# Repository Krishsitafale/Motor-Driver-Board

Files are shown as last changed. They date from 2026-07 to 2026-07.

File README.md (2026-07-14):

# TeleOps Motor Driver PCB
### International Rover Challenge (IRC) 2026 | Team Vishwa, VJTI






## Overview

The **TeleOps Motor Driver PCB** is a custom-designed embedded motor control board developed for **Team Vishwa, VJTI** for the **International Rover Challenge (IRC) 2026**.

The objective of this board was to consolidate multiple motor driver modules, PWM generators, power regulators, and peripheral interfaces into a single reliable PCB capable of controlling the rover's complete teleoperation subsystem.

Unlike conventional rover electronics that rely on several separate modules connected with extensive wiring, this PCB integrates all essential electronics into one compact system, improving reliability, reducing wiring complexity, and simplifying maintenance during competitions.

## Features

- ESP32-S3 based control unit
- Custom 5V Buck Converter (TPS54302)
- 10 High Current H-Bridge Drivers (BTN9970LV)
- PCA9685 16-Channel PWM Expander
- Encoder Interfaces
- GPS Interface
- Servo Motor Support
- Modular Connectors
- High Current PCB Layout
- Designed specifically for IRC Rover

## Hardware Specifications

| Component | Description |
|---|---|
| Microcontroller | ESP32-S3 |
| Buck Converter | TPS54302 |
| Motor Driver  | BTN9970LV |
| PWM Expansion | PCA9685 |
| Logic Voltage | 3.3V |
| Motor Supply  | 12V |
| PCB | 2 Layer |
| Communication | I²C, GPIO, PWM |

# System Architecture

                         12V Battery
                              │
                ┌─────────────┴─────────────┐
                │                           │
                │                    Motor Supply
                │                           │
                ▼                           ▼
      TPS54302 Buck Converter      10× BTN9970LV Drivers
                │
                ▼
             5V Rail
                │
                ▼
           ESP32-S3 MCU
                │
      ┌─────────┼─────────────────────────────┐
      │         │                             │
      │         │ I²C                         │ Native PWM
      │         ▼                             ▼
      │     PCA9685                    ESP32 PWM Outputs
      │   (16 Channel PWM)             (LEDC Peripheral)
      │         │                             │
      │         │                             ├──────── 2 DC Motor Drivers
      │         │                             │
      │         │                             └──────── 4 Servo Motors
      │         │
      │         ├──────── 8 Motor Driver PWM Inputs
      │         │
      │         └──────── Future Expansion
      │
      ├──────── Encoder Inputs
      │
      ├──────── GPS Interface
      │
      └──────── Programming Interface

## Motor Control Architecture

The rover requires control of multiple actuators with independent PWM channels. To efficiently utilize the ESP32's peripherals, the PWM generation is divided as follows:

| PWM Source | Devices Controlled |
|---|---|
| PCA9685(PWM Expander) | 8 High-Power DC Motor Drivers |
| ESP32 Native PWM | 2 High-Power DC Motor Drivers |
| ESP32 Native PWM | 4 Servo Motors |

This hybrid architecture reduces the processing load on the ESP32 while providing highly stable PWM signals for the drivetrain and robotic arm.

## Supported Actuators

### Drive System

- 6 Planetary DC Motors

### Robotic Arm

- 3 Stepper Motors
- 1 Planetary DC Motor
- 2 Worm Gear Motors
- 4 Servo Motors

### Sensors

- OE775 Quadrature Encoders
- GPS Module

## PCB Highlights

- Dedicated power plane for motor supply
- Optimized ground routing
- High-current copper traces
- Decoupling for every IC
- Modular connector layout
- Compact footprint
- Easy debugging headers
- Competition-ready wiring

## Testing

The PCB has successfully passed the following validation tests.

- Power Supply Verification
- ESP32 Programming
- Buck Converter Efficiency Test
- PCA9685 Communication
- PWM Signal Verification
- Motor Driver Validation
- Encoder Testing
- Servo Testing
- Thermal Performance
- Complete System Integration

## Future Improvements

- Closed Loop Motor Control
- Current Monitoring
- Battery Voltage Monitoring
- CAN Bus Support
- IMU Integration
- OTA Firmware Updates
- ROS 2 Compatibility

## Gallery

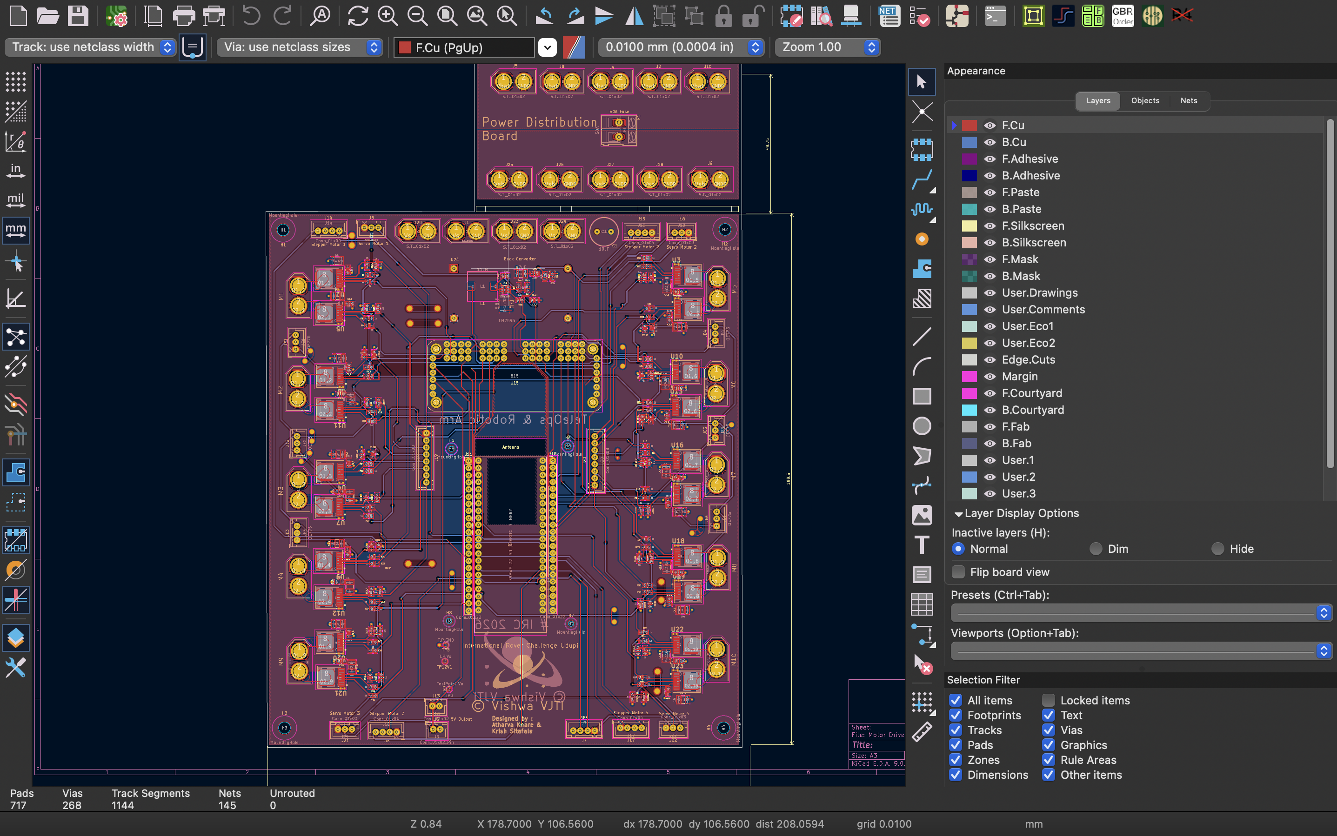
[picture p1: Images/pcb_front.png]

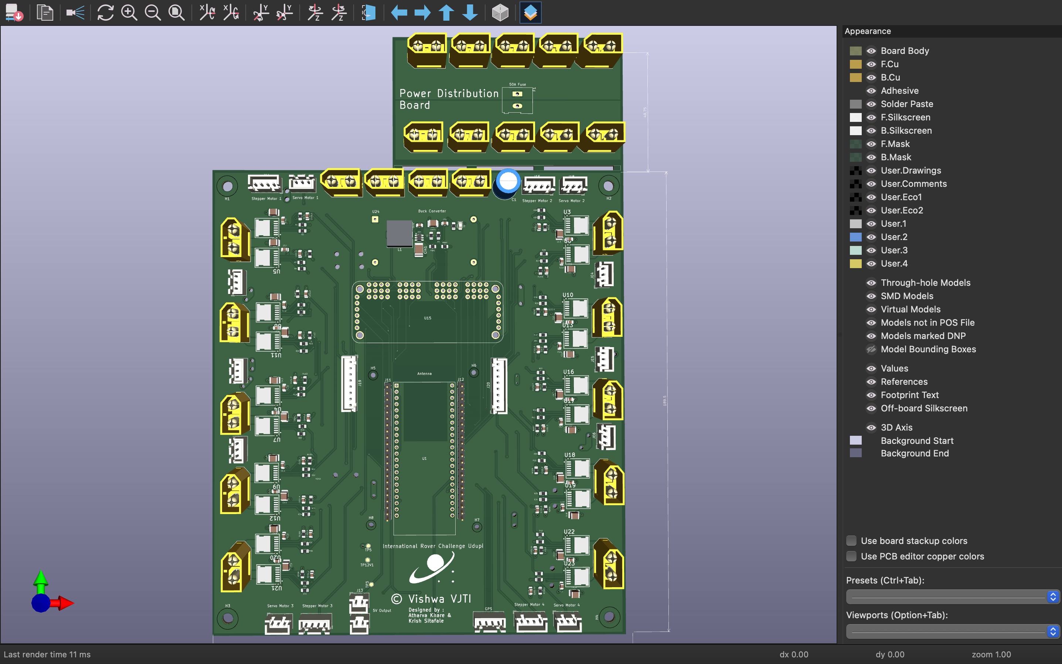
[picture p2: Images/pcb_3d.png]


## Acknowledgements

This PCB was designed and developed as part of the **Electronics Subsystem** of **Team Vishwa, VJTI** for the **International Rover Challenge (IRC) 2026**.

Special thanks to **Atharva Khare** for his invaluable guidance throughout the design, debugging, and testing phases of the project.

## Author

**Krish Sitafale**

Electronics & Telecommunication Engineering  
Veermata Jijabai Technological Institute (VJTI), Mumbai

Team Vishwa – IRC 2026

## License

This project is released for educational and research purposes.

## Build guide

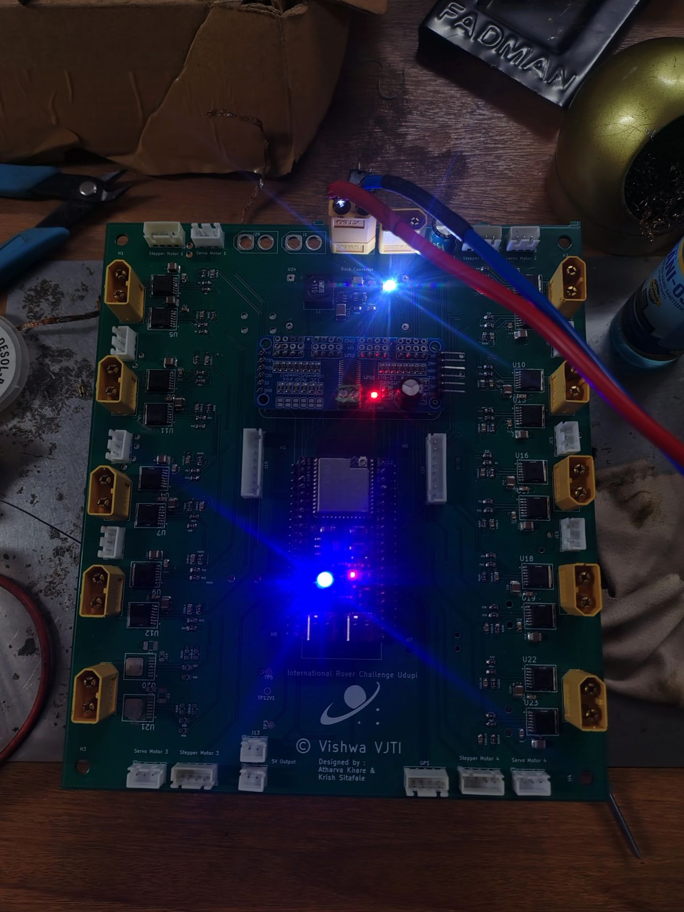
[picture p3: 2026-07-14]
Images/assembled_board.png

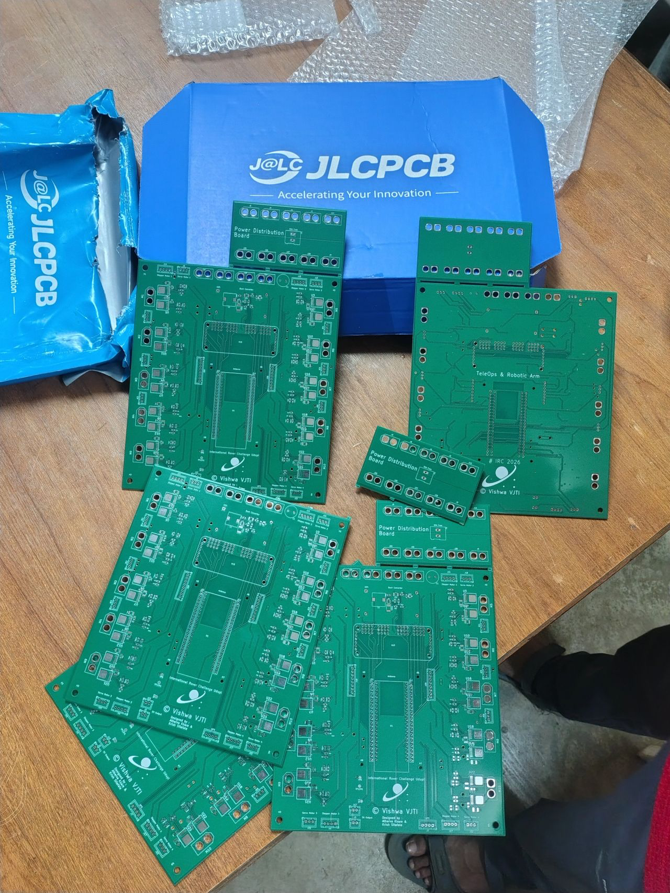
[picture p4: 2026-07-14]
Images/fabricated_board.png

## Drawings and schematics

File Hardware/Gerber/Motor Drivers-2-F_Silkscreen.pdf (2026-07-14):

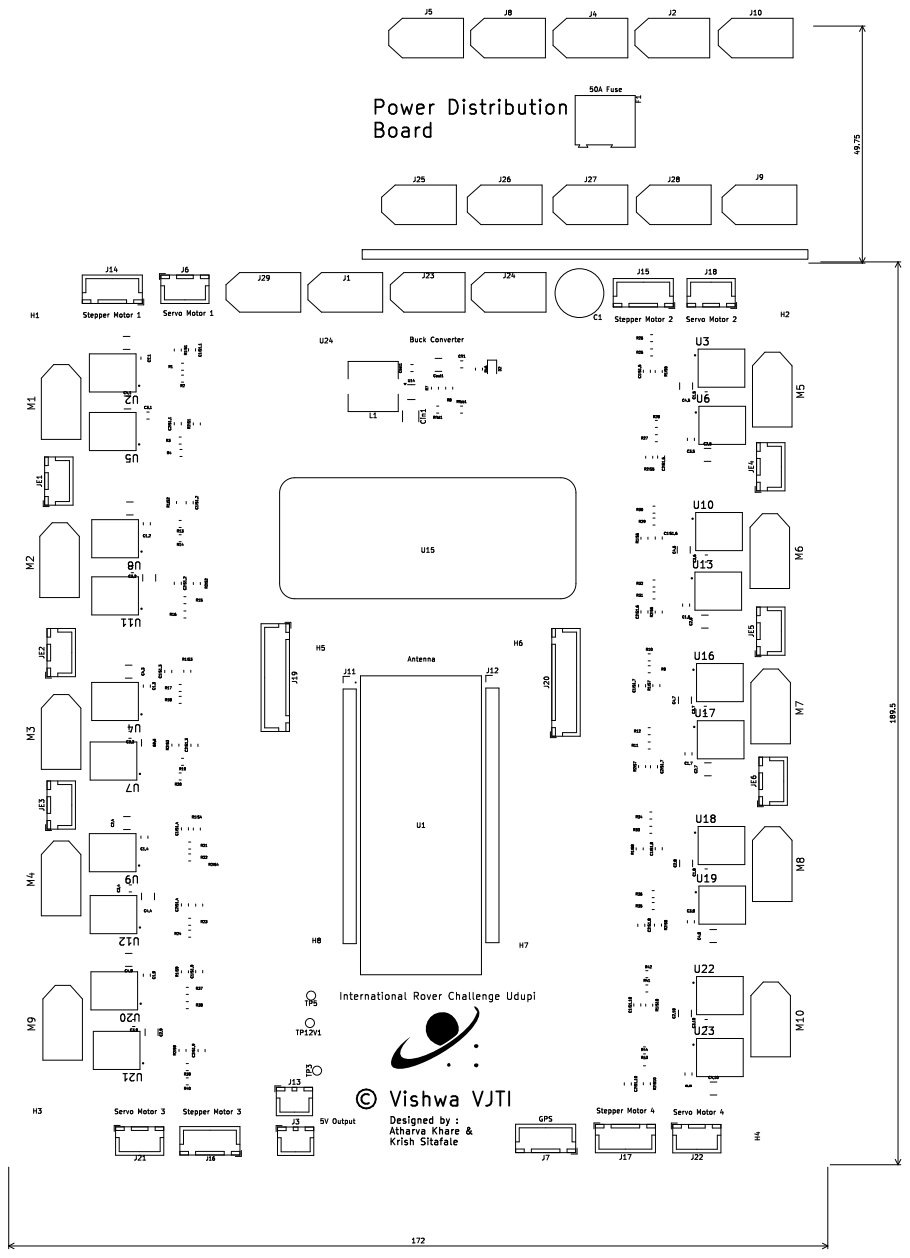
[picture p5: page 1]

Stepper Motor 2 Stepper Motor 1

Designed by : Atharva Khare &

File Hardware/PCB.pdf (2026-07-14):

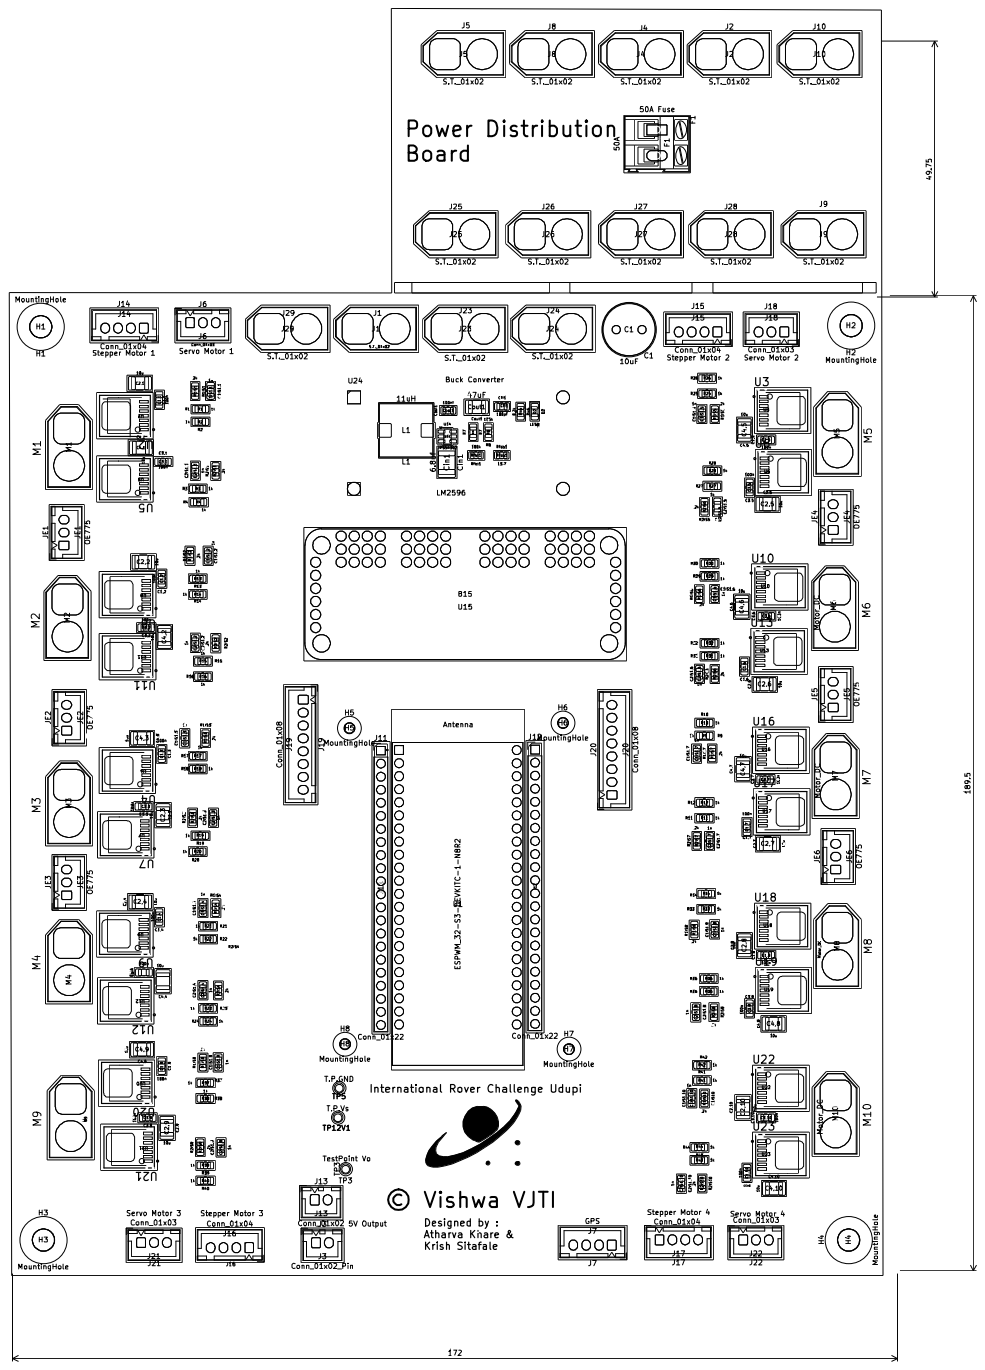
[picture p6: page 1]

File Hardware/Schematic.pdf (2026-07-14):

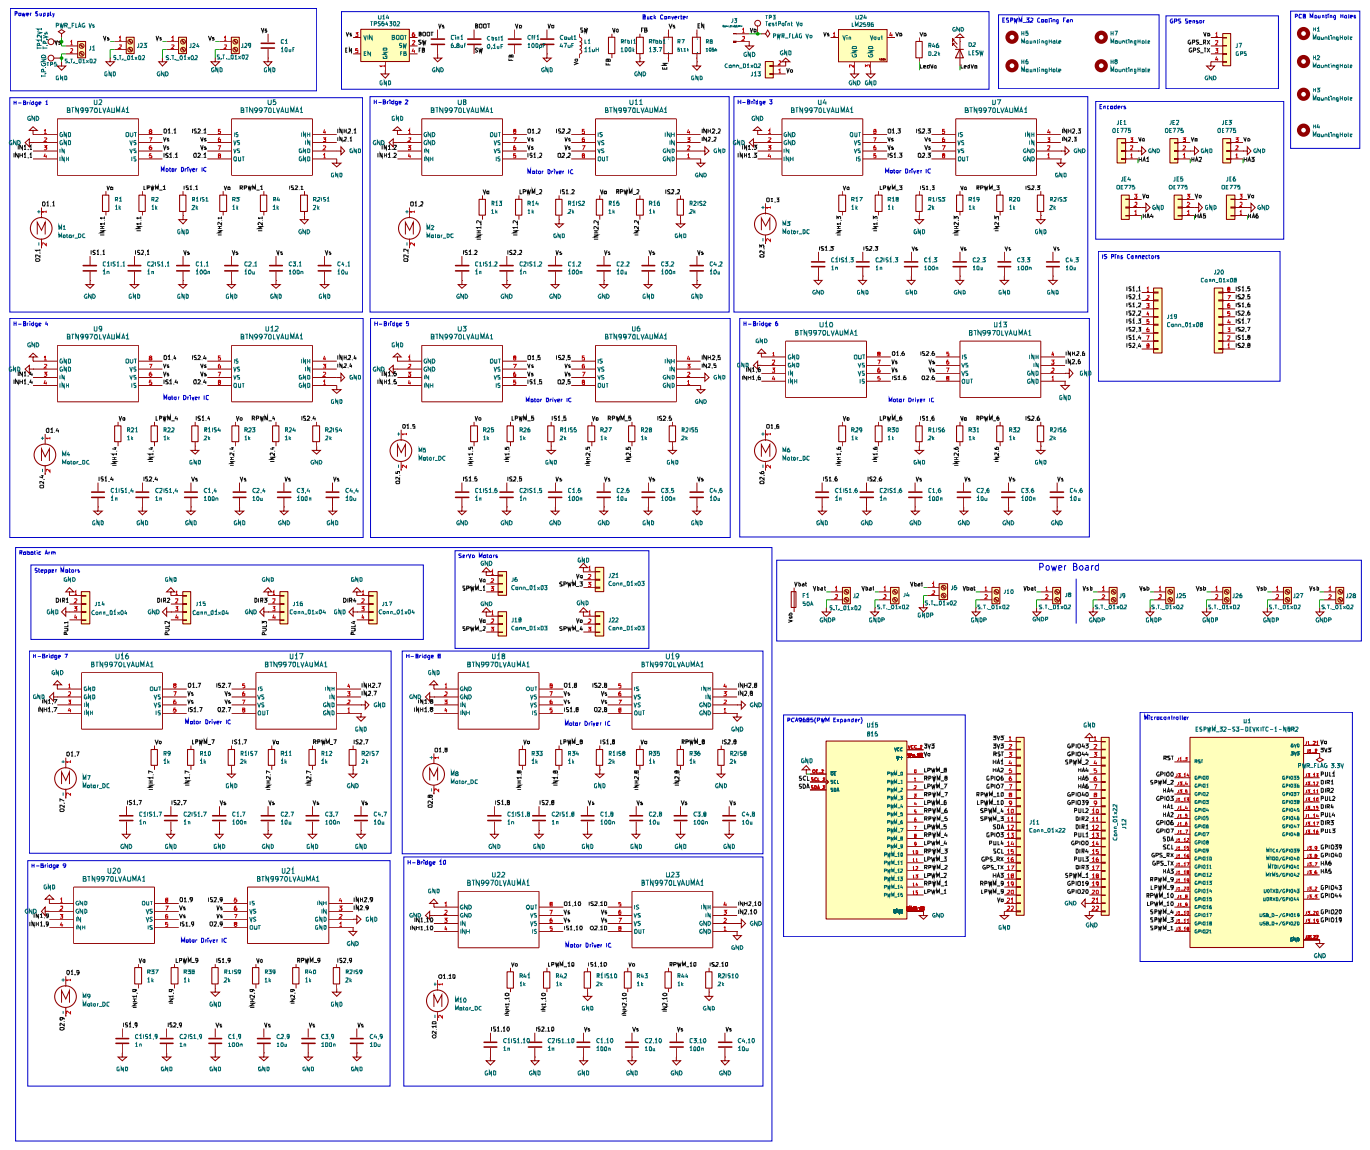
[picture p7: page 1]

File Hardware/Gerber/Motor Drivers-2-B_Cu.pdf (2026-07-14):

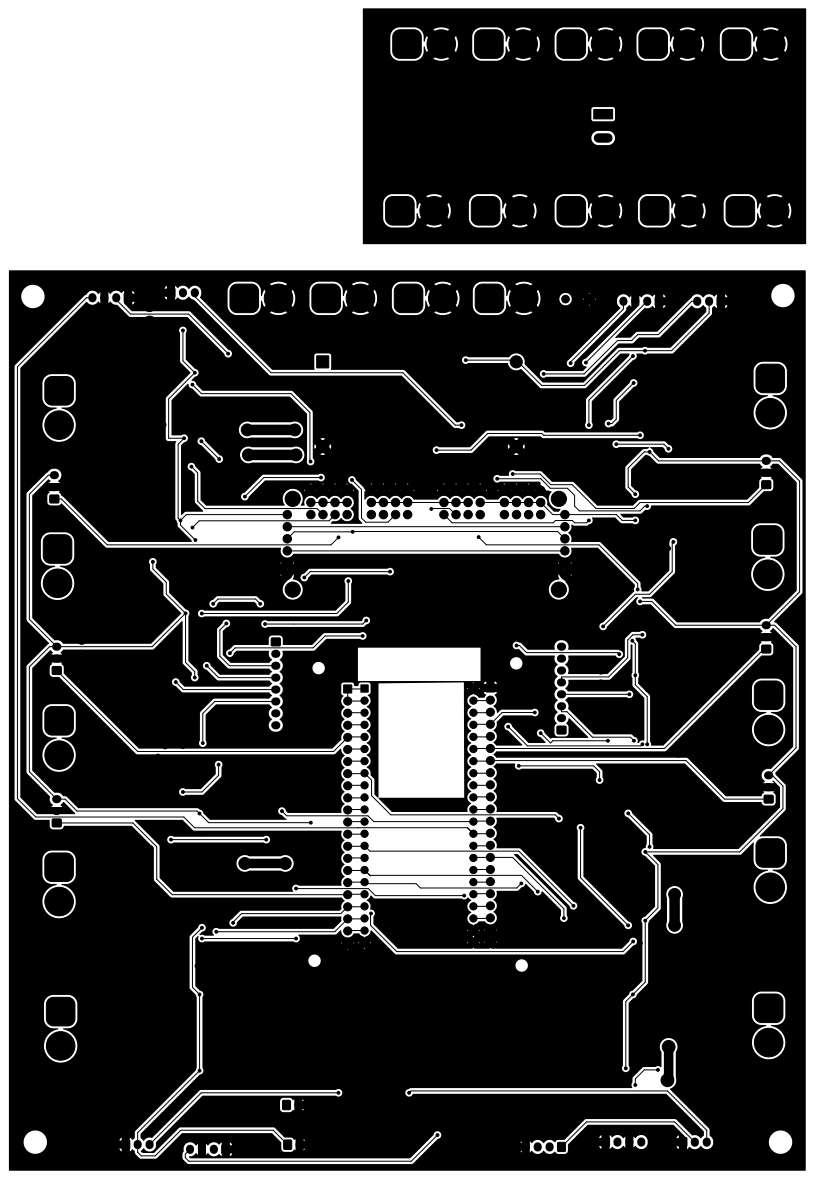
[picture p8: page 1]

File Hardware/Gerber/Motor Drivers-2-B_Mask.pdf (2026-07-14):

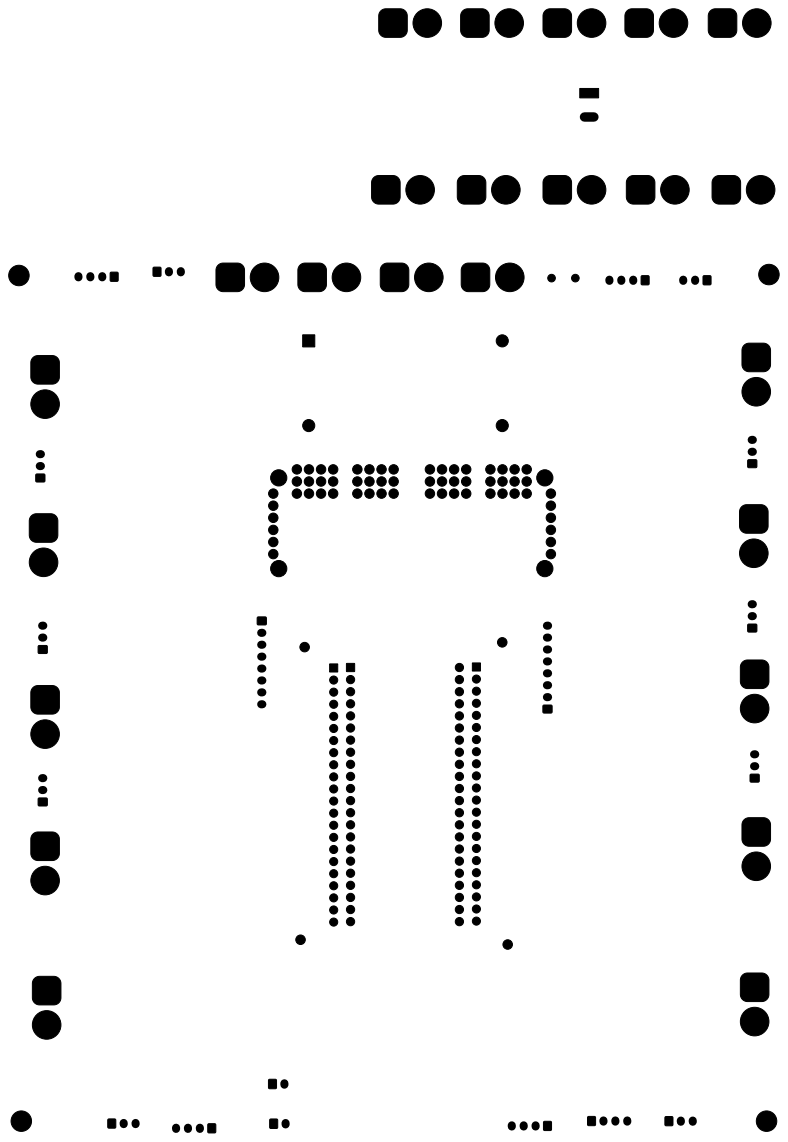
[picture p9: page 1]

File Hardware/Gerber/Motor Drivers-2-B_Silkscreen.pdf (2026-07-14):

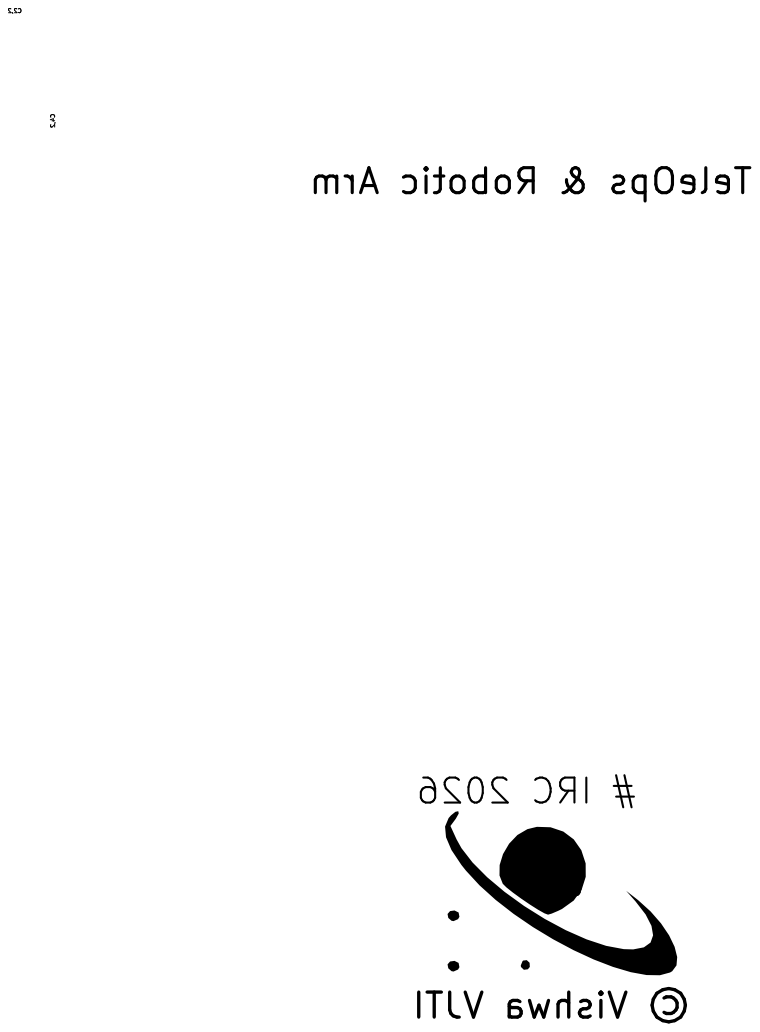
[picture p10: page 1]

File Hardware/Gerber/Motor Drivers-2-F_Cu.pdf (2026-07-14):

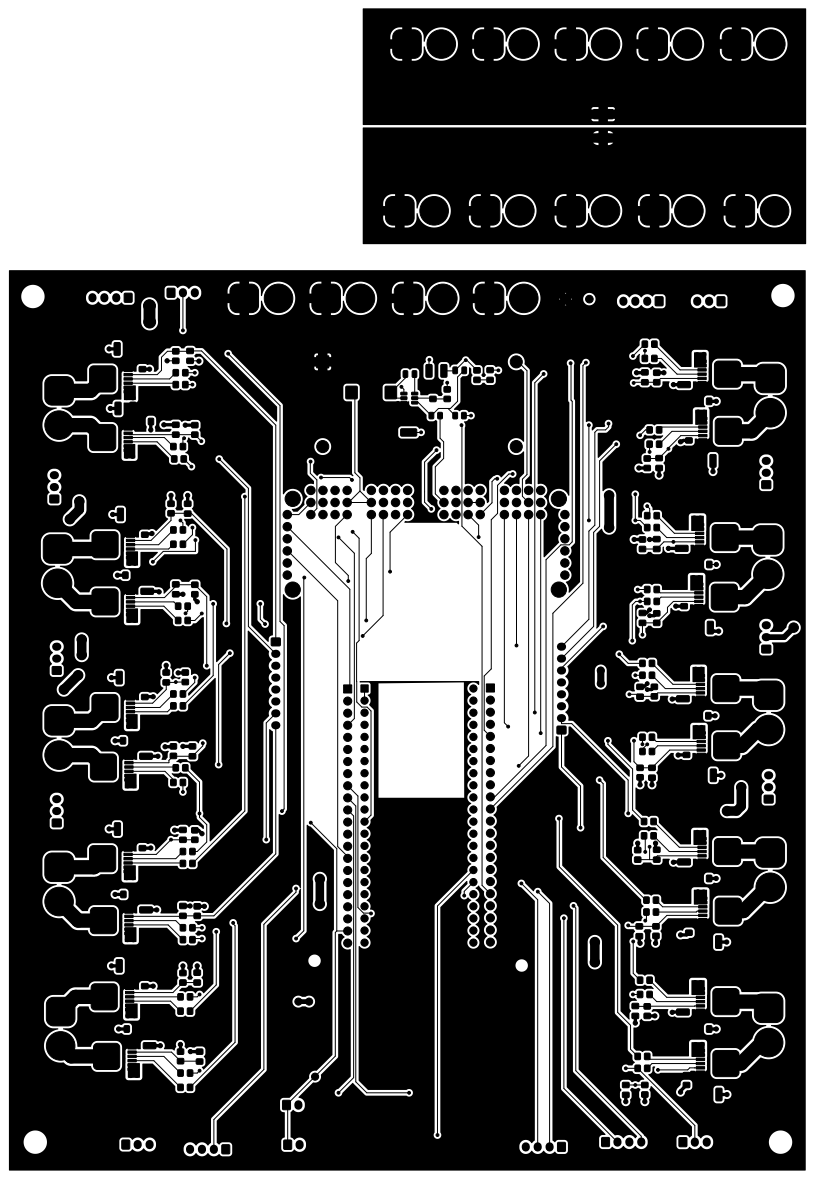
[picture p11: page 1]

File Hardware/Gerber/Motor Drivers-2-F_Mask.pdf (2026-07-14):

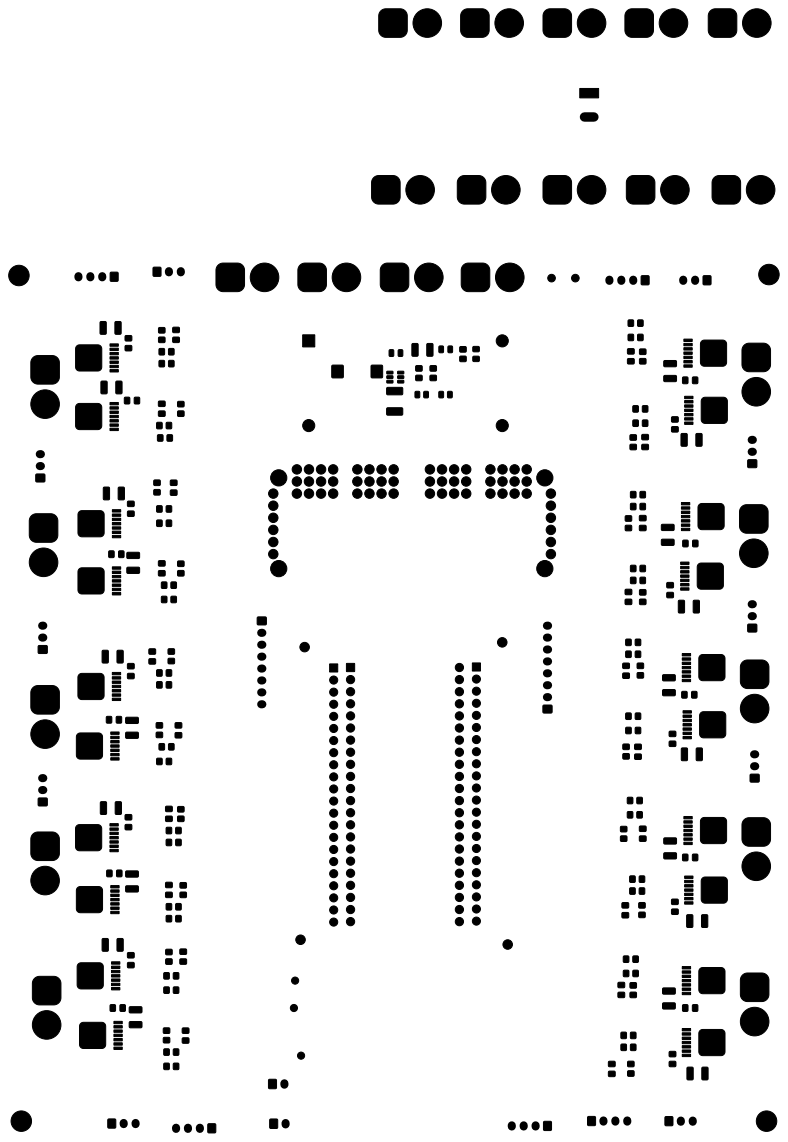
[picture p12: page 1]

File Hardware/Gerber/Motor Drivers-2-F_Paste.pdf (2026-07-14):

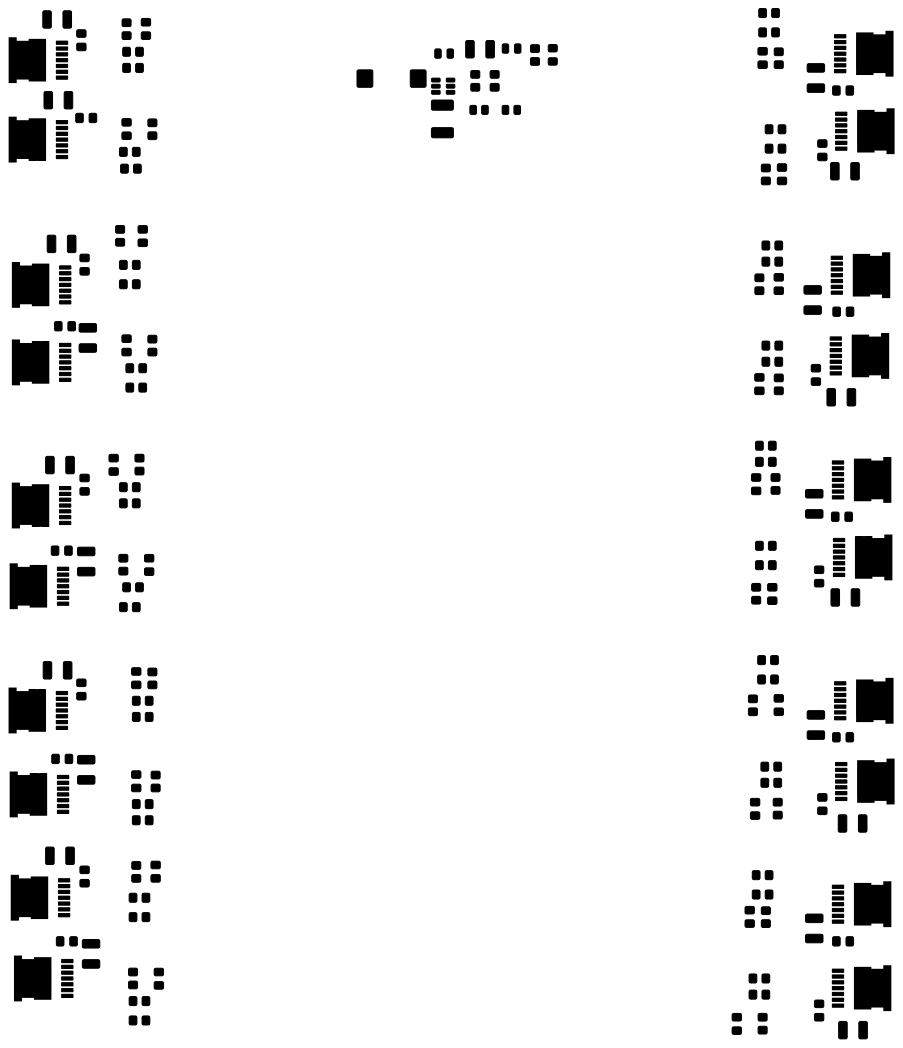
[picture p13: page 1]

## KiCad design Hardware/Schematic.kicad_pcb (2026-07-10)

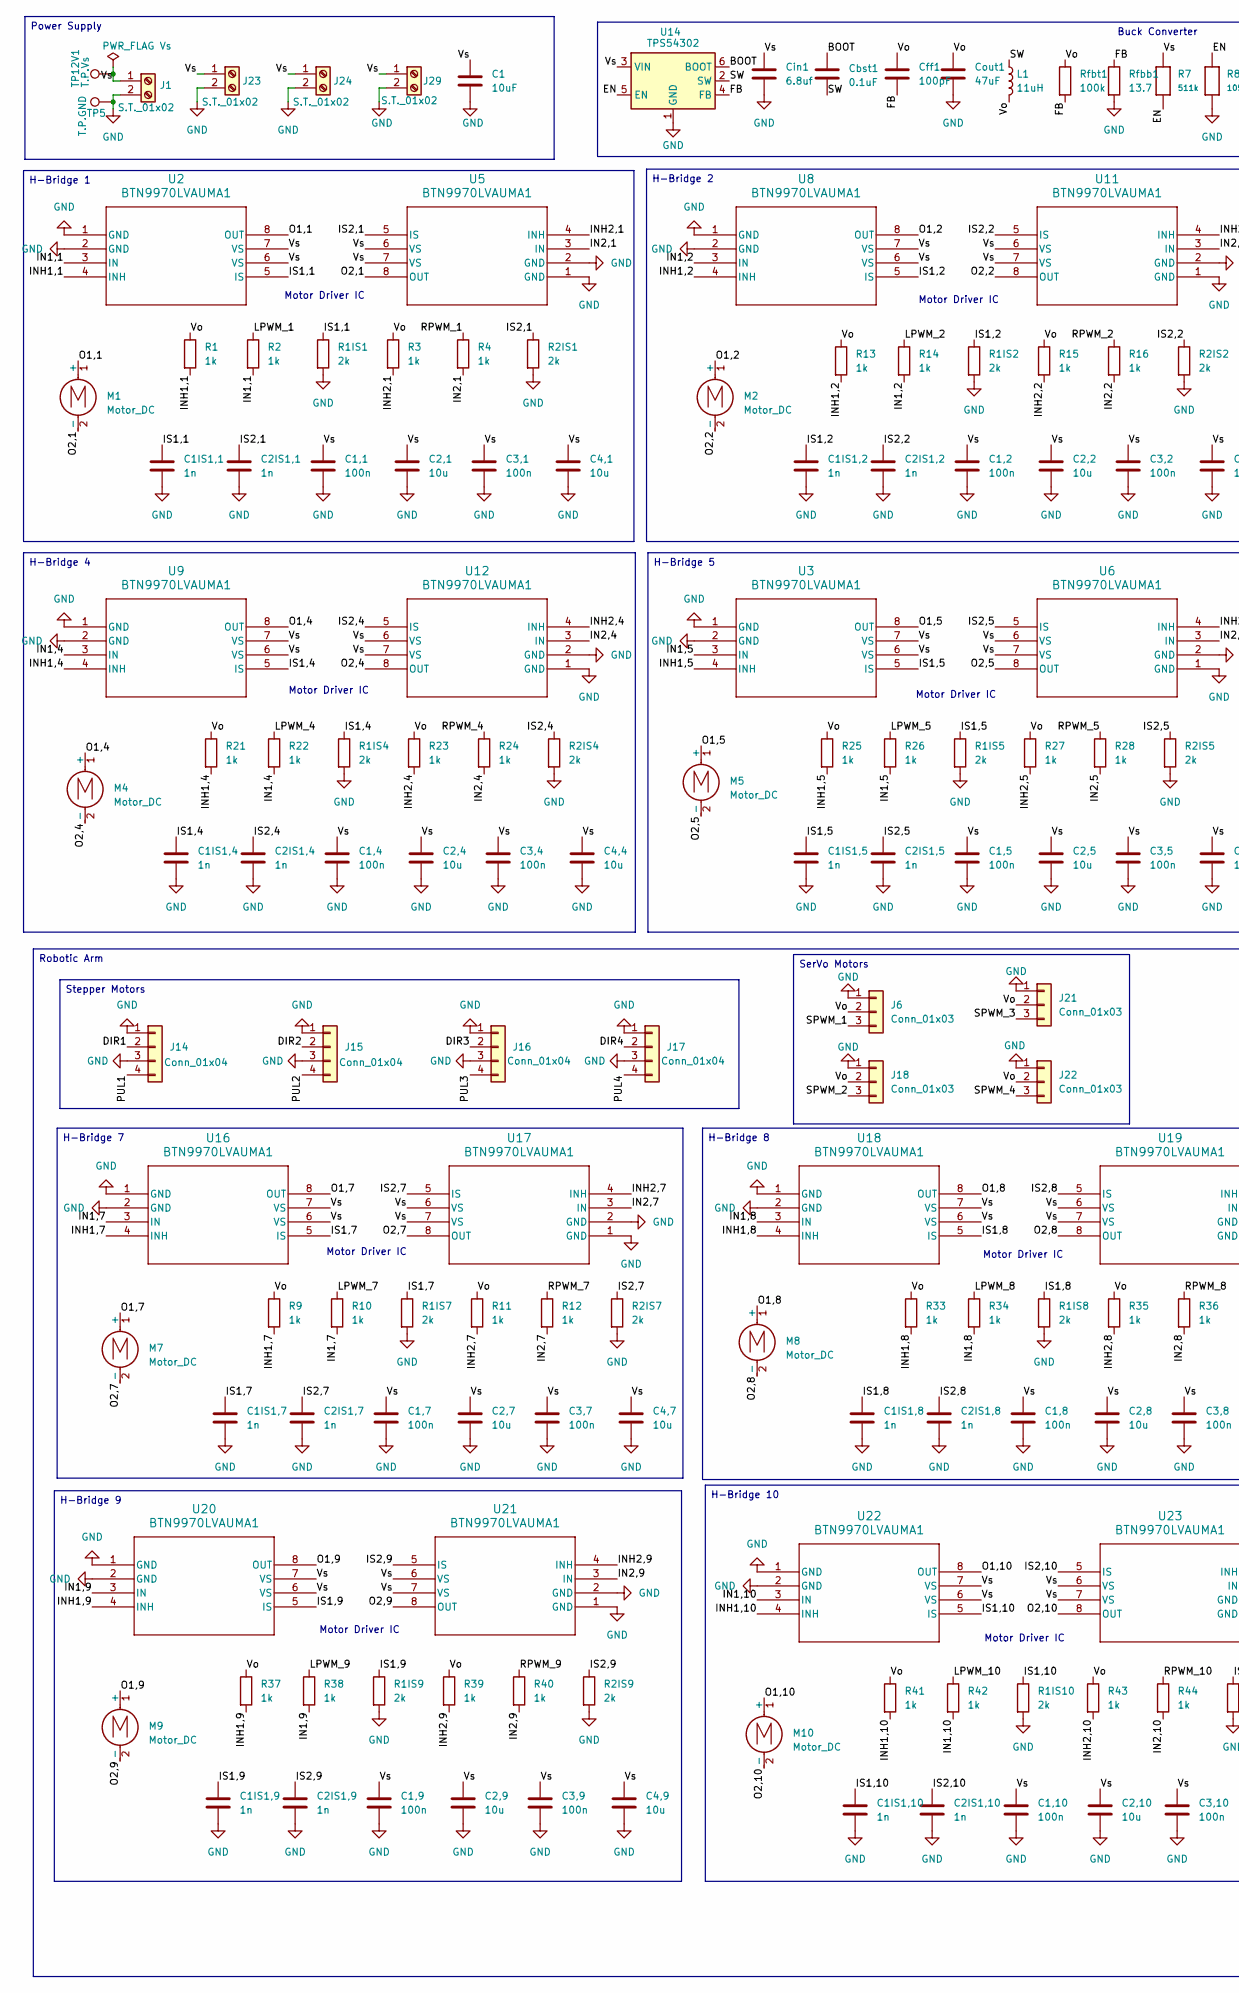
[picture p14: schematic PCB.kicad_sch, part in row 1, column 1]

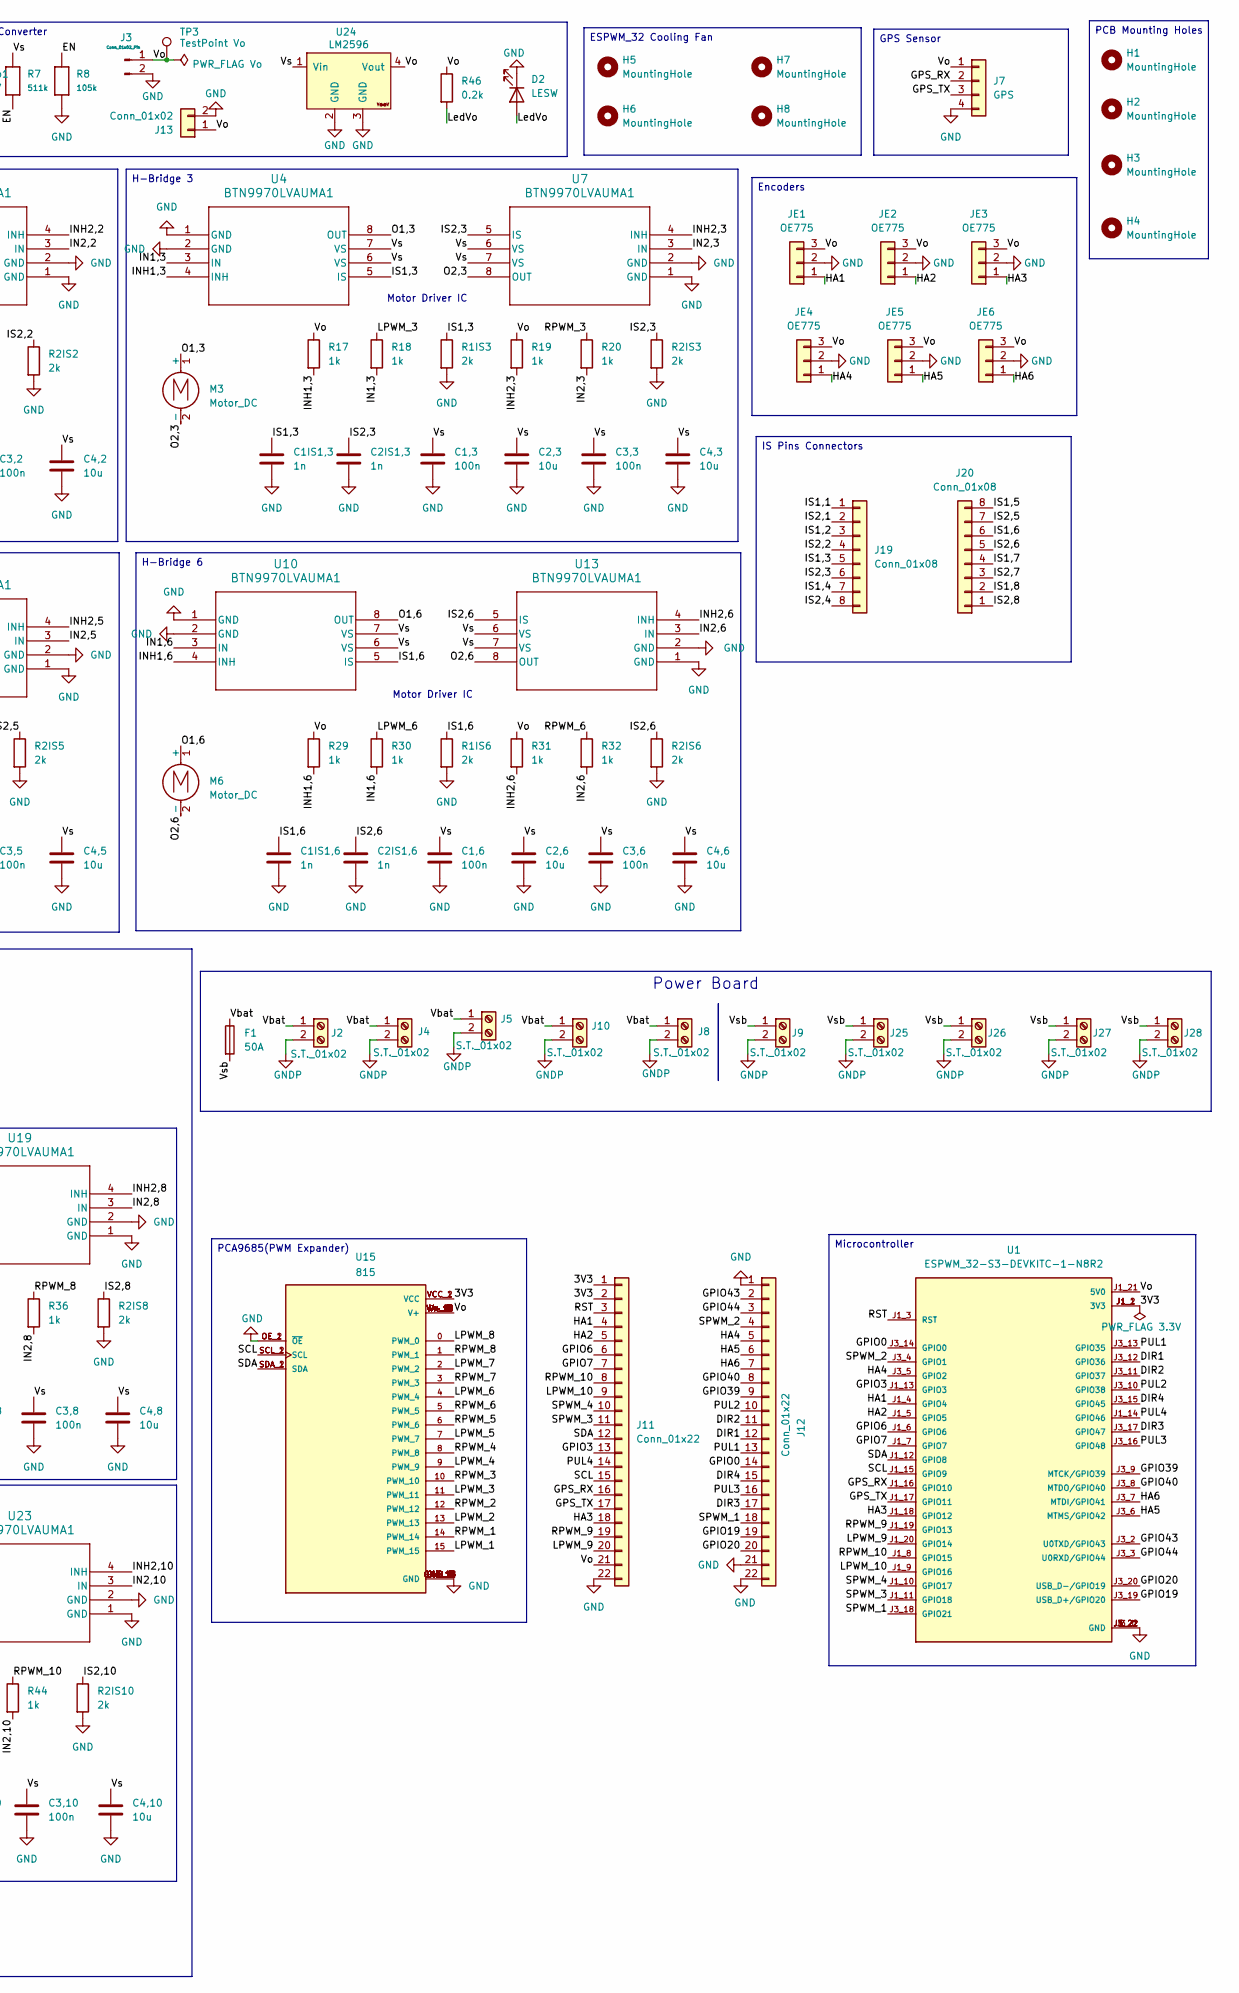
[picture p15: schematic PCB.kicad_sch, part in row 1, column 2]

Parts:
C1: 10uF; C_Radial_D10.0mm_H12.5mm_P5.00mm
C1,1, C1,2, C1,3, C1,4, C1,5, C1,6, C1,7, C1,8, C1,9, C1,10, C3,1, C3,2, C3,3, C3,4, C3,5, C3,6, C3,7, C3,8, C3,9, C3,10: 100n; C_0805_2012Metric_Pad1.18x1.45mm_HandSolder
C1IS1,1, C1IS1,2, C1IS1,3, C1IS1,4, C1IS1,5, C1IS1,6, C1IS1,7, C1IS1,8, C1IS1,9, C1IS1,10, C2IS1,1, C2IS1,2, C2IS1,3, C2IS1,4, C2IS1,5, C2IS1,6, C2IS1,7, C2IS1,8, C2IS1,9, C2IS1,10: 1n; C_0805_2012Metric_Pad1.18x1.45mm_HandSolder
C2,1, C2,2, C2,3, C2,4, C2,5, C2,6, C2,7, C2,8, C2,9, C2,10, C4,1, C4,2, C4,3, C4,4, C4,5, C4,6, C4,7, C4,8, C4,9, C4,10: 10u; C_1210_3225Metric_Pad1.33x2.70mm_HandSolder
Cbst1: 0.1uF; C_0805_2012Metric
Cff1: 100pF; C_0805_2012Metric
Cin1: 6.8uf; C_1812_4532Metric_Pad1.57x3.40mm_HandSolder
Cout1: 47uF; C_1210_3225Metric_Pad1.33x2.70mm_HandSolder
D2: LESW; LED_0805_2012Metric_Pad1.15x1.40mm_HandSolder
F1: 50A; TerminalBlock_Altech_AK300-2_P5.00mm
H1, H2, H3, H4: MountingHole; MountingHole_4.3mm_M4
H5, H6, H7, H8: MountingHole; MountingHole_2mm
J1, J2, J4, J5, J8, J9, J10, J23, J24, J25, J26, J27, J28, J29: S.T._01x02; AMASS_XT60-M_1x02_P7.20mm_Vertical
J3: Conn_01x02_Pin; JST_XH_B2B-XH-A_1x02_P2.50mm_Vertical
J6, J18, J21, J22: Conn_01x03; JST_XH_B3B-XH-A_1x03_P2.50mm_Vertical
J7: GPS; JST_XH_B4B-XH-A_1x04_P2.50mm_Vertical
J11, J12: Conn_01x22; PinHeader_1x22_P2.54mm_Vertical
J13: Conn_01x02; JST_XH_B2B-XH-A_1x02_P2.50mm_Vertical
J14, J15, J16, J17: Conn_01x04; JST_XH_B4B-XH-A_1x04_P2.50mm_Vertical
J19, J20: Conn_01x08; JST_XH_B8B-XH-A_1x08_P2.50mm_Vertical
JE1, JE2, JE3, JE4, JE5, JE6: OE775; JST_XH_B3B-XH-A_1x03_P2.50mm_Vertical
L1: 11uH; L_Wuerth_HCM-1052
M1, M2, M3, M4, M5, M6, M7, M8, M9, M10: Motor_DC; AMASS_XT60-M_1x02_P7.20mm_Vertical
R1, R2, R3, R4, R9, R10, R11, R12, R13, R14, R15, R16, R17, R18, R19, R20, R21, R22, R23, R24, R25, R26, R27, R28, R29, R30, R31, R32, R33, R34, R35, R36, R37, R38, R39, R40, R41, R42, R43, R44: 1k; R_0805_2012Metric_Pad1.20x1.40mm_HandSolder
R1IS1, R1IS2, R1IS3, R1IS4, R1IS5, R1IS6, R1IS7, R1IS8, R1IS9, R1IS10, R2IS1, R2IS2, R2IS3, R2IS4, R2IS5, R2IS6, R2IS7, R2IS8, R2IS9, R2IS10: 2k; R_0805_2012Metric_Pad1.20x1.40mm_HandSolder
R7: 511k; R_0805_2012Metric_Pad1.20x1.40mm_HandSolder
R8: 105k; R_0805_2012Metric_Pad1.20x1.40mm_HandSolder
R46: 0.2k; R_0805_2012Metric_Pad1.20x1.40mm_HandSolder
Rfbb1: 13.7; R_0805_2012Metric
Rfbt1: 100k; R_0805_2012Metric
TP3: TestPoint Vo; TestPoint_Pad_D1.5mm
TP5: T.P.GND; TestPoint_Pad_D1.5mm
TP12V1: T.P.Vs; TestPoint_Pad_D1.5mm
U1: ESPWM_32-S3-DEVKITC-1-N8R2; XCVR_ESP32-S3-DEVKITC-1-N8R2; PARTREV V1
U2, U3, U4, U5, U6, U7, U8, U9, U10, U11, U12, U13, U16, U17, U18, U19, U20, U21, U22, U23: BTN9970LVAUMA1; IFX-PG-HSOF-7-1-V
U14: TPS54302; SOT-23-6
U15: 815; MODULE_815; PARTREV C
U24: LM2596; YAAJ_DCDC_StepDown_LM2596

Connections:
/3V3: J11.1, J11.2, U1.J1_1 (3V3), U1.J1_2 (3V3), U15.VCC_1 (VCC), U15.VCC_2 (VCC)
/BOOT: Cbst1.1, U14.6 (BOOT)
/DIR1: J12.12, J14.2, U1.J3_12 (GPIO36)
/DIR2: J12.11, J15.2, U1.J3_11 (GPIO37)
/DIR3: J12.17, J16.2, U1.J3_17 (GPIO47)
/DIR4: J12.15, J17.2, U1.J3_15 (GPIO45)
/EN: R7.1, R8.2, U14.5 (EN)
/FB: Cff1.2, Rfbb1.1, Rfbt1.2, U14.4 (FB)
/GPIO0: J12.14, U1.J3_14 (GPIO0)
/GPIO3: J11.13, U1.J1_13 (GPIO3)
/GPIO6: J11.6, U1.J1_6 (GPIO6)
/GPIO7: J11.7, U1.J1_7 (GPIO7)
/GPIO19: J12.19, U1.J3_19 (USB_D+/GPIO20)
/GPIO20: J12.20, U1.J3_20 (USB_D-/GPIO19)
/GPIO39: J12.9, U1.J3_9 (MTCK/GPIO39)
/GPIO40: J12.8, U1.J3_8 (MTDO/GPIO40)
/GPIO43: J12.2, U1.J3_2 (U0TXD/GPIO43)
/GPIO44: J12.3, U1.J3_3 (U0RXD/GPIO44)
/GPS_RX: J7.2, J11.16, U1.J1_16 (GPIO10)
/GPS_TX: J7.3, J11.17, U1.J1_17 (GPIO11)
/HA1: J11.4, JE1.1, U1.J1_4 (GPIO4)
/HA2: J11.5, JE2.1, U1.J1_5 (GPIO5)
/HA3: J11.18, JE3.1, U1.J1_18 (GPIO12)
/HA4: J12.5, JE4.1, U1.J3_5 (GPIO2)
/HA5: J12.6, JE5.1, U1.J3_6 (MTMS/GPIO42)
/HA6: J12.7, JE6.1, U1.J3_7 (MTDI/GPIO41)
/IN1,1: R2.2, U2.3 (IN)
/IN1,2: R14.2, U8.3 (IN)
/IN1,3: R18.2, U4.3 (IN)
/IN1,4: R22.2, U9.3 (IN)
/IN1,5: R26.2, U3.3 (IN)
/IN1,6: R30.2, U10.3 (IN)
/IN1,7: R10.2, U16.3 (IN)
/IN1,8: R34.2, U18.3 (IN)
/IN1,9: R38.2, U20.3 (IN)
/IN1,10: R42.2, U22.3 (IN)
/IN2,1: R4.2, U5.3 (IN)
/IN2,2: R16.2, U11.3 (IN)
/IN2,3: R20.2, U7.3 (IN)
/IN2,4: R24.2, U12.3 (IN)
/IN2,5: R28.2, U6.3 (IN)
/IN2,6: R32.2, U13.3 (IN)
/IN2,7: R12.2, U17.3 (IN)
/IN2,8: R36.2, U19.3 (IN)
/IN2,9: R40.2, U21.3 (IN)
/IN2,10: R44.2, U23.3 (IN)
/INH1,1: R1.2, U2.4 (INH)
/INH1,2: R13.2, U8.4 (INH)
/INH1,3: R17.2, U4.4 (INH)
/INH1,4: R21.2, U9.4 (INH)
/INH1,5: R25.2, U3.4 (INH)
/INH1,6: R29.2, U10.4 (INH)
/INH1,7: R9.2, U16.4 (INH)
/INH1,8: R33.2, U18.4 (INH)
/INH1,9: R37.2, U20.4 (INH)
/INH1,10: R41.2, U22.4 (INH)
/INH2,1: R3.2, U5.4 (INH)
/INH2,2: R15.2, U11.4 (INH)
/INH2,3: R19.2, U7.4 (INH)
/INH2,4: R23.2, U12.4 (INH)
/INH2,5: R27.2, U6.4 (INH)
/INH2,6: R31.2, U13.4 (INH)
/INH2,7: R11.2, U17.4 (INH)
/INH2,8: R35.2, U19.4 (INH)
/INH2,9: R39.2, U21.4 (INH)
/INH2,10: R43.2, U23.4 (INH)
/IS1,1: C1IS1,1.1, J19.1, R1IS1.1, U2.5 (IS)
/IS1,2: C1IS1,2.1, J19.3, R1IS2.1, U8.5 (IS)
/IS1,3: C1IS1,3.1, J19.5, R1IS3.1, U4.5 (IS)
/IS1,4: C1IS1,4.1, J19.7, R1IS4.1, U9.5 (IS)
/IS1,5: C1IS1,5.1, J20.8, R1IS5.1, U3.5 (IS)
/IS1,6: C1IS1,6.1, J20.6, R1IS6.1, U10.5 (IS)
/IS1,7: C1IS1,7.1, J20.4, R1IS7.1, U16.5 (IS)
/IS1,8: C1IS1,8.1, J20.2, R1IS8.1, U18.5 (IS)
/IS1,9: C1IS1,9.1, R1IS9.1, U20.5 (IS)
/IS1,10: C1IS1,10.1, R1IS10.1, U22.5 (IS)
/IS2,1: C2IS1,1.1, J19.2, R2IS1.1, U5.5 (IS)
/IS2,2: C2IS1,2.1, J19.4, R2IS2.1, U11.5 (IS)
/IS2,3: C2IS1,3.1, J19.6, R2IS3.1, U7.5 (IS)
/IS2,4: C2IS1,4.1, J19.8, R2IS4.1, U12.5 (IS)
/IS2,5: C2IS1,5.1, J20.7, R2IS5.1, U6.5 (IS)
/IS2,6: C2IS1,6.1, J20.5, R2IS6.1, U13.5 (IS)
/IS2,7: C2IS1,7.1, J20.3, R2IS7.1, U17.5 (IS)
/IS2,8: C2IS1,8.1, J20.1, R2IS8.1, U19.5 (IS)
/IS2,9: C2IS1,9.1, R2IS9.1, U21.5 (IS)
/IS2,10: C2IS1,10.1, R2IS10.1, U23.5 (IS)
/LPWM_1: R2.1, U15.15 (PWM_15)
/LPWM_2: R14.1, U15.13 (PWM_13)
/LPWM_3: R18.1, U15.11 (PWM_11)
/LPWM_4: R22.1, U15.9 (PWM_9)
/LPWM_5: R26.1, U15.7 (PWM_7)
/LPWM_6: R30.1, U15.4 (PWM_4)
/LPWM_7: R10.1, U15.2 (PWM_2)
/LPWM_8: R34.1, U15.0 (PWM_0)
/LPWM_9: J11.20, R38.1, U1.J1_20 (GPIO14)
/LPWM_10: J11.9, R42.1, U1.J1_9 (GPIO16)
/LedVo: D2.2 (A), R46.2
/O1,1: M1.1 (+), U2.8 (OUT)
/O1,2: M2.1 (+), U8.8 (OUT)
/O1,3: M3.1 (+), U4.8 (OUT)
/O1,4: M4.1 (+), U9.8 (OUT)
/O1,5: M5.1 (+), U3.8 (OUT)
/O1,6: M6.1 (+), U10.8 (OUT)
/O1,7: M7.1 (+), U16.8 (OUT)
/O1,8: M8.1 (+), U18.8 (OUT)
/O1,9: M9.1 (+), U20.8 (OUT)
/O1,10: M10.1 (+), U22.8 (OUT)
/O2,1: M1.2 (-), U5.8 (OUT)
/O2,2: M2.2 (-), U11.8 (OUT)
/O2,3: M3.2 (-), U7.8 (OUT)
/O2,4: M4.2 (-), U12.8 (OUT)
/O2,5: M5.2 (-), U6.8 (OUT)
/O2,6: M6.2 (-), U13.8 (OUT)
/O2,7: M7.2 (-), U17.8 (OUT)
/O2,8: M8.2 (-), U19.8 (OUT)
/O2,9: M9.2 (-), U21.8 (OUT)
/O2,10: M10.2 (-), U23.8 (OUT)
/PUL1: J12.13, J14.4, U1.J3_13 (GPIO35)
/PUL2: J12.10, J15.4, U1.J3_10 (GPIO38)
/PUL3: J12.16, J16.4, U1.J3_16 (GPIO48)
/PUL4: J11.14, J17.4, U1.J1_14 (GPIO46)
/RPWM_1: R4.1, U15.14 (PWM_14)
/RPWM_2: R16.1, U15.12 (PWM_12)
/RPWM_3: R20.1, U15.10 (PWM_10)
/RPWM_4: R24.1, U15.8 (PWM_8)
/RPWM_5: R28.1, U15.6 (PWM_6)
/RPWM_6: R32.1, U15.5 (PWM_5)
/RPWM_7: R12.1, U15.3 (PWM_3)
/RPWM_8: R36.1, U15.1 (PWM_1)
/RPWM_9: J11.19, R40.1, U1.J1_19 (GPIO13)
/RPWM_10: J11.8, R44.1, U1.J1_8 (GPIO15)
/RST: J11.3, U1.J1_3 (RST)
/SCL: J11.15, U1.J1_15 (GPIO9), U15.SCL_1 (SCL), U15.SCL_2 (SCL)
/SDA: J11.12, U1.J1_12 (GPIO8), U15.SDA_1 (SDA), U15.SDA_2 (SDA)
/SPWM_1: J6.3, J12.18, U1.J3_18 (GPIO21)
/SPWM_2: J12.4, J18.3, U1.J3_4 (GPIO1)
/SPWM_3: J11.11, J21.3, U1.J1_11 (GPIO18)
/SPWM_4: J11.10, J22.3, U1.J1_10 (GPIO17)
/SW: Cbst1.2, L1.1, U14.2 (SW)
/Vbat: F1.1, J2.1, J4.1, J5.1, J8.1, J10.1
/Vo: Cff1.1, Cout1.1, J3.1, J6.2, J7.1, J11.21, J13.1, J18.2, J21.2, J22.2, JE1.3, JE2.3, JE3.3, JE4.3, JE5.3, JE6.3, L1.2, R1.1, R3.1, R9.1, R11.1, R13.1, R15.1, R17.1, R19.1, R21.1, R23.1, R25.1, R27.1, R29.1, R31.1, R33.1, R35.1, R37.1, R39.1, R41.1, R43.1, R46.1, Rfbt1.1, TP3.1, U1.J1_21 (5V0), U15.V+_1 (V+), U15.V+_2 (V+), U15.V+_3 (V+), U15.V+_4 (V+), U15.V+_5 (V+), U15.V+_6 (V+), U15.V+_7 (V+), U15.V+_8 (V+), U15.V+_9 (V+), U15.V+_10 (V+), U15.V+_11 (V+), U15.V+_12 (V+), U15.V+_13 (V+), U15.V+_14 (V+), U15.V+_15 (V+), U15.V+_16 (V+), U15.V+_17 (V+), U15.V+_18 (V+), U24.4 (Vout)
/Vs: C1.1, C1,1.1, C1,2.1, C1,3.1, C1,4.1, C1,5.1, C1,6.1, C1,7.1, C1,8.1, C1,9.1, C1,10.1, C2,1.1, C2,2.1, C2,3.1, C2,4.1, C2,5.1, C2,6.1, C2,7.1, C2,8.1, C2,9.1, C2,10.1, C3,1.1, C3,2.1, C3,3.1, C3,4.1, C3,5.1, C3,6.1, C3,7.1, C3,8.1, C3,9.1, C3,10.1, C4,1.1, C4,2.1, C4,3.1, C4,4.1, C4,5.1, C4,6.1, C4,7.1, C4,8.1, C4,9.1, C4,10.1, Cin1.1, J1.1, J23.1, J24.1, J29.1, R7.2, TP12V1.1, U2.6 (VS), U2.7 (VS), U3.6 (VS), U3.7 (VS), U4.6 (VS), U4.7 (VS), U5.6 (VS), U5.7 (VS), U6.6 (VS), U6.7 (VS), U7.6 (VS), U7.7 (VS), U8.6 (VS), U8.7 (VS), U9.6 (VS), U9.7 (VS), U10.6 (VS), U10.7 (VS), U11.6 (VS), U11.7 (VS), U12.6 (VS), U12.7 (VS), U13.6 (VS), U13.7 (VS), U14.3 (VIN), U16.6 (VS), U16.7 (VS), U17.6 (VS), U17.7 (VS), U18.6 (VS), U18.7 (VS), U19.6 (VS), U19.7 (VS), U20.6 (VS), U20.7 (VS), U21.6 (VS), U21.7 (VS), U22.6 (VS), U22.7 (VS), U23.6 (VS), U23.7 (VS), U24.1 (Vin)
/Vsb: F1.2, J9.1, J25.1, J26.1, J27.1, J28.1
GND: C1.2, C1,1.2, C1,2.2, C1,3.2, C1,4.2, C1,5.2, C1,6.2, C1,7.2, C1,8.2, C1,9.2, C1,10.2, C1IS1,1.2, C1IS1,2.2, C1IS1,3.2, C1IS1,4.2, C1IS1,5.2, C1IS1,6.2, C1IS1,7.2, C1IS1,8.2, C1IS1,9.2, C1IS1,10.2, C2,1.2, C2,2.2, C2,3.2, C2,4.2, C2,5.2, C2,6.2, C2,7.2, C2,8.2, C2,9.2, C2,10.2, C2IS1,1.2, C2IS1,2.2, C2IS1,3.2, C2IS1,4.2, C2IS1,5.2, C2IS1,6.2, C2IS1,7.2, C2IS1,8.2, C2IS1,9.2, C2IS1,10.2, C3,1.2, C3,2.2, C3,3.2, C3,4.2, C3,5.2, C3,6.2, C3,7.2, C3,8.2, C3,9.2, C3,10.2, C4,1.2, C4,2.2, C4,3.2, C4,4.2, C4,5.2, C4,6.2, C4,7.2, C4,8.2, C4,9.2, C4,10.2, Cin1.2, Cout1.2, D2.1 (K), J1.2, J3.2, J6.1, J7.4, J11.22, J12.1, J12.21, J12.22, J13.2, J14.1, J14.3, J15.1, J15.3, J16.1, J16.3, J17.1, J17.3, J18.1, J21.1, J22.1, J23.2, J24.2, J29.2, JE1.2, JE2.2, JE3.2, JE4.2, JE5.2, JE6.2, R1IS1.2, R1IS2.2, R1IS3.2, R1IS4.2, R1IS5.2, R1IS6.2, R1IS7.2, R1IS8.2, R1IS9.2, R1IS10.2, R2IS1.2, R2IS2.2, R2IS3.2, R2IS4.2, R2IS5.2, R2IS6.2, R2IS7.2, R2IS8.2, R2IS9.2, R2IS10.2, R8.1, Rfbb1.2, TP5.1, U1.J1_22 (GND), U1.J3_1 (GND), U1.J3_21 (GND), U1.J3_22 (GND), U2.1 (GND), U2.2 (GND), U3.1 (GND), U3.2 (GND), U4.1 (GND), U4.2 (GND), U5.1 (GND), U5.2 (GND), U6.1 (GND), U6.2 (GND), U7.1 (GND), U7.2 (GND), U8.1 (GND), U8.2 (GND), U9.1 (GND), U9.2 (GND), U10.1 (GND), U10.2 (GND), U11.1 (GND), U11.2 (GND), U12.1 (GND), U12.2 (GND), U13.1 (GND), U13.2 (GND), U14.1 (GND), U15.GND_1 (GND), U15.GND_2 (GND), U15.GND_3 (GND), U15.GND_4 (GND), U15.GND_5 (GND), U15.GND_6 (GND), U15.GND_7 (GND), U15.GND_8 (GND), U15.GND_9 (GND), U15.GND_10 (GND), U15.GND_11 (GND), U15.GND_12 (GND), U15.GND_13 (GND), U15.GND_14 (GND), U15.GND_15 (GND), U15.GND_16 (GND), U15.GND_17 (GND), U15.GND_18 (GND), U15.OE_1 (~OE), U15.OE_2 (~OE), U16.1 (GND), U16.2 (GND), U17.1 (GND), U17.2 (GND), U18.1 (GND), U18.2 (GND), U19.1 (GND), U19.2 (GND), U20.1 (GND), U20.2 (GND), U21.1 (GND), U21.2 (GND), U22.1 (GND), U22.2 (GND), U23.1 (GND), U23.2 (GND), U24.2 (GND), U24.3 (GND)
GNDP: J2.2, J4.2, J5.2, J8.2, J9.2, J10.2, J25.2, J26.2, J27.2, J28.2

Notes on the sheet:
Motor Driver IC
H-Bridge 7
H-Bridge 9
H-Bridge 6
Encoders
Microcontroller
SerVo Motors
GPS Sensor
H-Bridge 1
PCB Mounting Holes
H-Bridge 4
Buck Converter
PCA9685(PWM Expander)
H-Bridge 5
ESPWM_32 Cooling Fan
H-Bridge 10
H-Bridge 3
H-Bridge 8
H-Bridge 2
Power Board
Stepper Motors
Robotic Arm
Power Supply
IS Pins Connectors

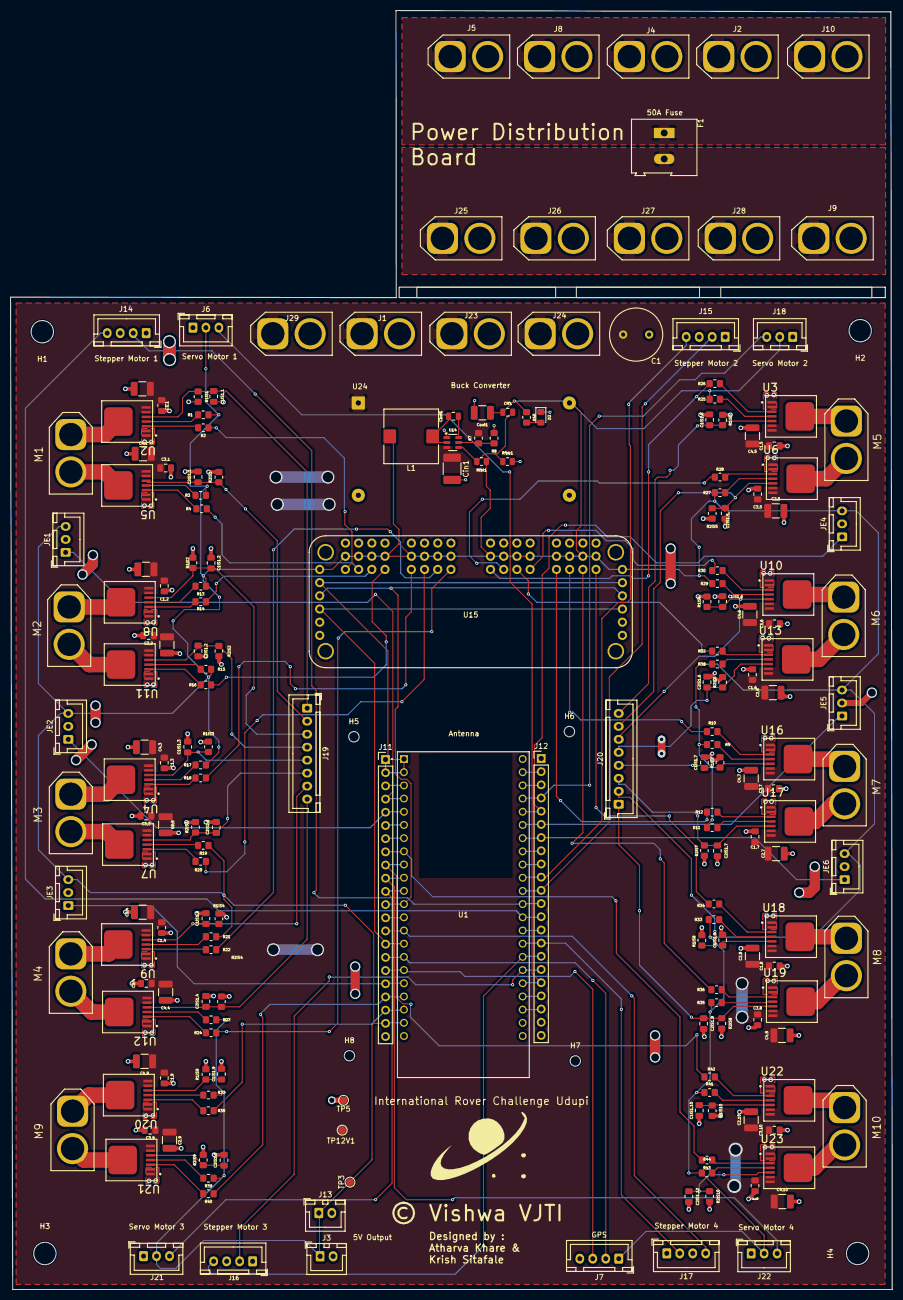
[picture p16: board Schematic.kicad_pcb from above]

Board: 2 copper layers, 169.8 x 246.3 mm, 213 parts (0 on the bottom side), 145 nets.

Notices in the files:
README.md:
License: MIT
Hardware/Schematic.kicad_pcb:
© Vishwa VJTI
